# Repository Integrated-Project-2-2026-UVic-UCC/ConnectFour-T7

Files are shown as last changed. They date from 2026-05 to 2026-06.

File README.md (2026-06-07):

<div align="center">

# Autonomous Connect 4 Machine
### Integrated Project II · Mechatronics Engineering · UVic-UCC 2026




[]()
[]()

*A fully autonomous physical Connect 4 machine: the ESP32 detects each piece drop with photoelectric sensors, decides the best move, and physically delivers the piece using a motorized lead screw dispenser.*

</div>

---

## Table of Contents

- [About the Project](#about-the-project)
- [How It Works](#how-it-works)
- [Mechanical Design](#mechanical-design)
- [Electronics](#electronics)
- [Software](#software)
- [Hardware Components](#hardware-components)
- [Getting Started](#getting-started)
- [Current Status](#current-status)
- [Team](#team)
- [License](#license)

---

## About the Project

This project is developed as part of **Integrated Project II** in the **Mechatronics Engineering** degree at the Universitat de Vic – Universitat Central de Catalunya (UVic-UCC).

The goal is to build a machine that plays **Connect 4 autonomously** against a human opponent. The machine detects the human's move through **photoelectric sensors**, decides which column to play, moves a **3D-printed piece dispenser** along a lead screw to the correct position, and drops a piece with a **servo motor** — all controlled by an **ESP32**.

The robot does not use an artificial intelligence engine. Instead, it follows a predefined logical strategy: win if possible, block the opponent, or otherwise play an available column. All game communication is handled through the **Serial Monitor**.

---

## How It Works

```
Human drops a piece
        │
        ▼
Photoelectric sensor (one per column)
detects the piece passing through
        │
        ▼
ESP32 updates the board state
        │
        ▼
Software selects the column to play
(win > block > random available column)
        │
        ▼
Stepper motor moves the dispenser
along the lead screw to the target column
        │
        ▼
Servo motor pushes the ramp and releases one piece
        │
        ▼
Piece falls into the board
        │
        ▼
Game state shown through the Serial Monitor
```

> **Note:** Piece recovery and board reset are performed manually between games.

---

## Mechanical Design

The mechanical design is organized into two main assemblies, all modeled in PTC Creo, exported as STL for 3D printing, and documented with technical drawings.

**Board structure assembly** — represents the game board and holds the structure upright:
- **Foot L** and **Foot R** — the two legs of the structure
- **Bottom Cover** — closes the structure and assembles onto the base
- **Connect 4** — the main board frame with the 7 × 6 grid of columns
- **Connect 4 Cover** — the front cover that closes the playing grid

**Dispenser and linear-motion assembly** — carries and releases the pieces:
- **Support Foot** and **Dispenser Support Bar** — hold the dispenser in place
- **Motor Support** — holds the stepper motor at one end of the lead screw
- **Bearing Support** — holds the bearing at the opposite end of the lead screw
- **Dispenser Part 1** and **Dispenser Part 2** — form the dispenser body

The pieces are stored horizontally inside the dispenser. To drop a piece, an internal ramp reorients it from horizontal to vertical so it falls correctly into the selected column, and a servo motor pushes the ramp downward to release one piece at a time. The whole dispenser slides along the lead screw to align with any of the seven columns.

---

## Electronics

The electrical system is based on an **ESP32** microcontroller, which manages all inputs and outputs of the robot:
- Reads the photoelectric (IR) sensors to detect the column played by the human
- Controls the stepper motor driver to move the dispenser horizontally
- Activates the servo motor to release a piece
- Provides the electrical interface between software, sensors, and actuators

The ESP32 works with 3.3 V logic, and an external power supply feeds the stepper motor and servo. All components share a common ground to keep a correct signal reference. The schematic was designed with EasyEDA.

---

## Software

- **Microcontroller:** ESP32
- **Language:** C++ (Arduino)
- **Key modules:**
  - `detection` — reads photoelectric sensors and maps them to a column index
  - `motion` — stepper step generation and position control
  - `servo` — piece release timing and control
  - `game` — board state, win/block detection, move selection
  - `serial` — Serial Monitor communication (prompts and game status)

The board is handled as a 6-row by 7-column matrix. The code initializes the board, manages player and robot moves, validates that columns are not full, and detects winning conditions (horizontal, vertical, and diagonal) as well as draws.

Two final versions of the system are provided:
- **Automatic Detection Mode** — the player's move is detected automatically by the photoelectric sensors, which identify the played column.
- **Manual Input Mode** — a backup version where the player enters the column number through the Serial Monitor, in case the sensors fail.

---

## Hardware Components

| Component | Description | 
|---|---|
| ESP32 | Main microcontroller — game logic, motor and sensor control |
| NEMA17 stepper motor | X-axis movement via lead screw |
| Stepper driver | Motor driver for step/direction control |
| Lead screw | Linear X-axis mechanism |
| Linear guide + carriage | Supports and guides the dispenser |
| 9g micro servo | Releases one piece at a time from the dispenser |
| Photoelectric / IR sensors | One per column, detect the played column |
| Series resistors | Required for reliable photoelectric detection |
| External power supply | Powers the stepper motor and servo |
| Connect 4 board | 7 × 6 grid with sensor holes at the top |

---

## Getting Started

### Prerequisites

- [Arduino IDE](https://www.arduino.cc/en/software) or [PlatformIO](https://platformio.org/) with ESP32 board support
- ESP32 board package installed
- Required libraries:
  - `AccelStepper` — stepper motor control
  - `ESP32Servo` — servo control

### Flash to ESP32

1. Open the project in Arduino IDE or PlatformIO
2. Select board: **ESP32 Dev Module**
3. Connect ESP32 via USB
4. Upload

> **Warning:** Make sure the sensors, motor, and servo are connected before powering on, and that the external power supply for the motor and servo is on.

---

## Current Status

| Phase | Task | Status |
|---|---|---|
| 1 | Initial design and planning | Done |
| 2 | Component procurement | Done |
| 3 | 3D printing — dispenser and mechanical parts | Done |
| 3 | Electronics wiring and assembly | Done |
| 3 | Individual component testing (sensors, motor, servo) | Done |
| 4 | Full system integration | Done |
| 4 | Software validation on real hardware | Done |
| 5 | Final calibration and demo | Done |

---

## Team

| Name | Role |
|---|---|
| Arnau Arcarons | Project Manager |
| Pau Vila | Mechanical Leader |
| Victor Ruiz | Electronics Leader |
| Albert Llimós | Programming Leader |

> Project supervised by Moisès and Clara, faculty of Mechatronics Engineering at UVic-UCC.

---

## License

This project is licensed under the **GNU General Public License v3.0**.
See the [`LICENSE`](LICENSE) file for full details.

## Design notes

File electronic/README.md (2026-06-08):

# Electronics

This folder contains the final electronic documentation of the autonomous Connect Four robot developed by Team 7 for the Integrated Projects II course at UVic-UCC.

The electronic system connects the control software with the physical hardware of the machine. It is responsible for reading the player move sensors, controlling the stepper motor driver, activating the piece dispenser servo, and managing the basic electrical interface between all components.

---

## Folder Contents

This folder includes the main electrical schematic of the prototype and the datasheets of the key electronic components used in the system.

| File | Description |
|---|---|
| `IP_2.pdf` | Final electrical schematic of the system, created with EasyEDA. It shows the connections between the ESP32 controller, sensors, stepper driver, servo motor, power supply and common ground. |
| `A1.3 esp32-s3_datasheet_en.pdf` | Datasheet of the ESP32-S3 microcontroller, used as the main controller reference for GPIO, electrical characteristics and pin functions. |
| `A4988.PDF` | Datasheet/reference document for the A4988 stepper motor driver used to control the NEMA17 stepper motor. |
| `README.md` | Documentation file describing the purpose and contents of the electronics folder. |

---

## Electronic System Overview

The electronic system is centred on the ESP32 microcontroller. The ESP32 receives input signals from the column sensors and sends control signals to the actuators of the machine.

The system performs the following main tasks:

1. Detecting the column selected by the human player.
2. Sending STEP and DIR signals to the A4988 stepper motor driver.
3. Moving the NEMA17 stepper motor along the horizontal axis.
4. Activating the 9 g servo motor to release one piece.
5. Reading the limit switch used as a mechanical reference.
6. Coordinating the electrical behaviour of the full prototype.

---

## Main Electronic Components

| Component | Function | Interface |
|---|---|---|
| ESP32 / ESP32-S3 | Main controller of the system | GPIO / PWM / Serial |
| A4988 stepper motor driver | Controls the NEMA17 stepper motor | STEP / DIR |
| NEMA17 stepper motor | Moves the dispenser horizontally | Driven by A4988 |
| 9 g servo motor | Opens and closes the dispenser gate | PWM |
| Column sensors | Detect the column used by the human player | Digital inputs |
| Limit switch | Provides a reference position for the axis | Digital input |
| External power supply | Powers the motor and actuator system | Power input |
| Common ground | Shared electrical reference | GND |

---

## Electrical Schematic

The electrical schematic is provided in:

```text
IP_2.pdf

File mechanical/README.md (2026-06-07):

## Project Description
This repository contains the mechanical design of a robot capable of playing the Connect Four game. The mechanical system provides the physical structure of the game board and the mechanism responsible for storing, positioning, and dropping the playing pieces into the correct column.

The design is organized into two main assemblies: the board structure, which holds the playing grid, and the dispenser and linear-motion assembly, which moves along the board and releases the pieces one by one.

## Project Structure
During the development process, the mechanical design was divided into two main assemblies:
1. Board structure assembly
2. Dispenser and linear-motion assembly

Each part was modeled in PTC Creo, exported as an STL file for 3D printing, and documented with its corresponding technical drawing.

## Board Structure Assembly
This assembly represents the game board and provides the supporting frame of the robot. It is composed of:
* **Foot L** and **Foot R** – the two legs that hold the structure upright
* **Bottom Cover** – the lower cover that closes the structure and is assembled onto the base
* **Connect 4** – the main board frame containing the 6×7 grid of columns
* **Connect 4 Cover** – the front cover that closes the playing grid

The two feet and the bottom cover are assembled together to form the base, onto which the board frame and its cover are mounted.

## Dispenser and Linear-Motion Assembly
The second assembly is mounted on its own support and is responsible for carrying and releasing the pieces. It includes:
* **Support Foot** – the additional leg of this assembly
* **Dispenser Support Bar** – the bar that links the support and holds the dispenser in place
* **Motor Support** – the bracket that holds the stepper motor at one end of the lead screw
* **Bearing Support** – the bracket that holds the bearing at the opposite end of the lead screw
* **Dispenser Part 1**, **Dispenser Part 2** and the **Dispenser Support Bar** – the parts that form the dispenser body

A support element attaches the carriage and its bushing to the dispenser, allowing the whole dispenser to slide along the lead screw.

## Piece Dispensing Mechanism
The pieces are stored horizontally inside the dispenser. To drop a piece, the dispenser uses an internal ramp that reorients the piece from a horizontal to a vertical position, so that it can fall correctly into the selected column.

A servo motor mounted on the dispenser pushes the ramp downward, releasing one piece at a time.

## Linear-Motion System
The dispenser moves horizontally along the board by means of a lead screw (worm screw):
* The **Motor Support** holds the stepper motor at the beginning of the lead screw
* The **Bearing Support** holds the bearing at the end of the lead screw
* The carriage, attached to the dispenser, travels along the screw to position the dispenser over the desired column

This allows the robot to align the dispenser precisely with any of the seven columns before releasing a piece.

## File Formats and Repository Structure
For each part, three file formats are provided. The files are organized into three folders:
* **STL_3D_Parts** – the 3D models in STL format, ready for 3D printing
* **Creo_Files** – the original PTC Creo part files (`.prt`), including the Creo session trail file
* **Technical_Drawings** – the technical drawings (blueprints) of each part in PDF format

## Current Project Status
The mechanical design has reached a functional state where:
* The board structure and base are fully modeled and assembled
* The dispenser and its ramp mechanism convert pieces from horizontal to vertical for correct release
* The servo-driven dropping mechanism has been integrated into the dispenser
* The linear-motion system positions the dispenser over each column using a lead screw
* All parts are documented with STL models, Creo files, and technical drawings ready for manufacturing

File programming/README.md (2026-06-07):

## Project Description

This project implements the control software for a robot capable of playing the Connect Four game. The program acts as the robot's control system, managing the game logic, player interaction, and the robot's decision-making process.

The system allows a complete game between the player and the robot by validating moves, managing turns, and determining the final result (win, loss, or draw).

## Project Structure

During the development process, the project was divided into three main parts:

1. Robot decision-making
2. Player interaction
3. Mechanical control and piece launching

In the final version, the implementation of an artificial intelligence system was not considered necessary. Instead, the robot follows a predefined logical strategy to make its decisions.

## Code Functionality

The code manages a 6-row by 7-column matrix that represents the game board. The main functionalities include:

* Board initialization
* Management of player and robot moves
* Validation of moves to ensure that columns are not full
* Detection of winning conditions (horizontal, vertical, and diagonal)
* Detection of draw situations when the board is full

## Robot Decision Logic

The robot follows a simple three-step strategy:

1. Check for an immediate winning move
2. Block the player if they are about to win
3. Select a random available column if no better option is found

## Player Interaction

The LCD display originally planned for the project was not implemented. Instead, all communication with the player is performed through the computer's Serial Monitor.

The serial interface allows the user to:

* Select which player starts the game
* Enter player moves
* Display game status messages
* Restart the game after a match ends

## Sensor and Mechanical Testing

Several tests were carried out to validate the operation of the photoelectric sensors. Although the sensors work correctly in most situations, occasional detection failures were observed.

For this reason, the development process was divided into several independent test programs:

* Sensor testing code
* Stepper motor movement testing code
* Servo-based piece launching testing code
* Main logic code that integrates player interaction and the robot's decision-making strategy

## Final Implementations

Two final versions of the system were developed:

### Automatic Detection Mode

In this version, the player's move is detected automatically by a photoelectric sensor, which identifies the column where the piece has been dropped. The robot then analyzes the board and performs its move according to the predefined logic.

### Manual Input Mode

Since the sensors may occasionally fail, a backup version was also developed. In this mode, the player enters the column number through the Serial Monitor after each move. The robot then updates the board, analyzes the game state, and performs its move using the same logical decision-making process.

## Current Project Status

The project has reached a functional state where:

* The robot can play a complete game of Connect Four
* Player interaction is managed through the Serial Monitor
* The mechanical launching system has been tested
* Sensor detection has been implemented and evaluated
* A backup manual mode ensures reliable operation even if the sensors fail

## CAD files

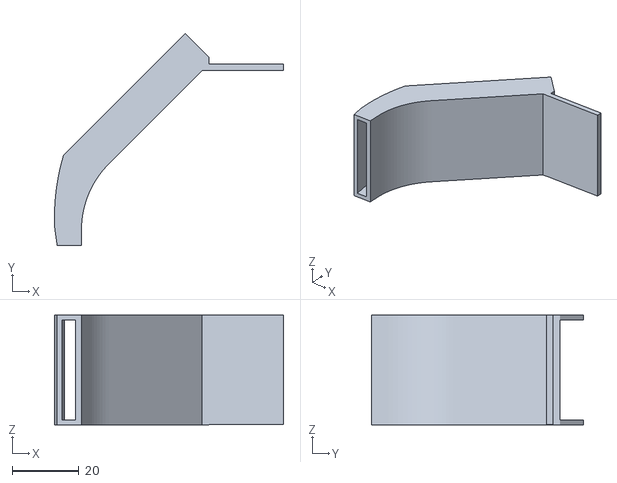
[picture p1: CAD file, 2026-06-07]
mechanical/STL_3D_Parts/dispenser_part_2.stl
68.7 x 63.5 x 33.0

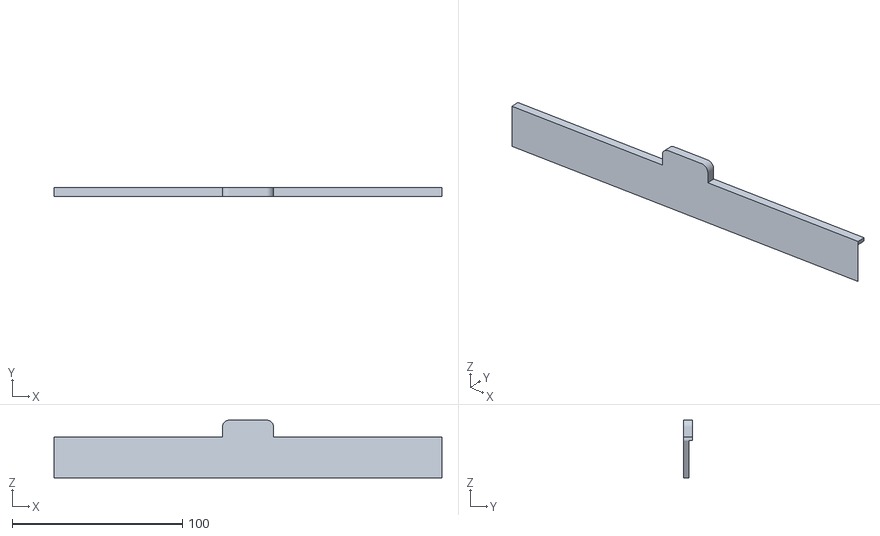
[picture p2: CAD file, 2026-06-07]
mechanical/STL_3D_Parts/bottom_cover.stl
228.0 x 5.00 x 34.0

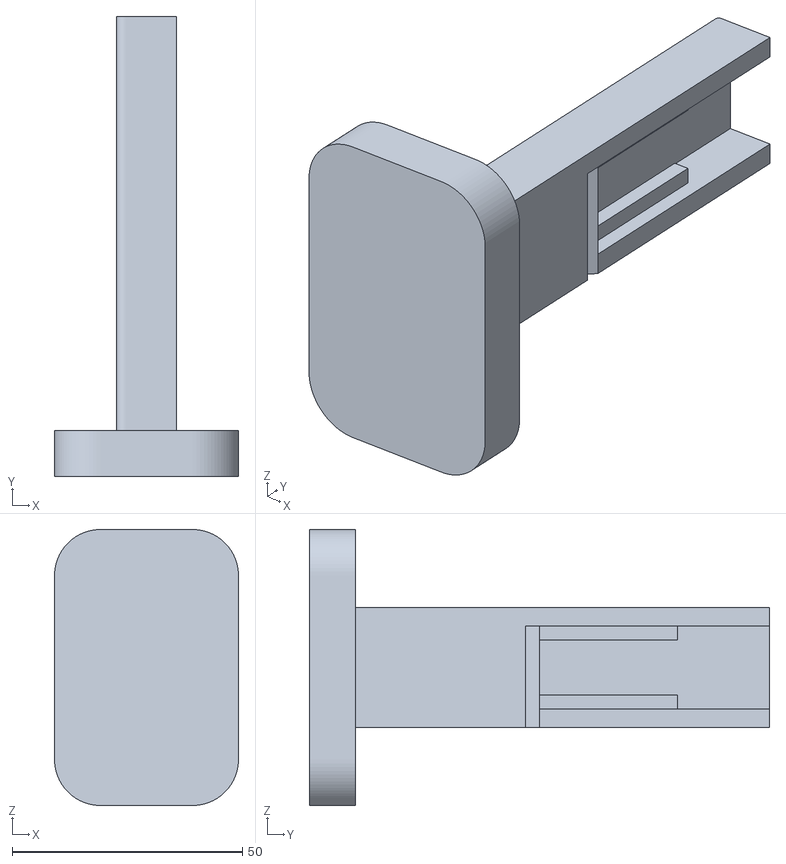
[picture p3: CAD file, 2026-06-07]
mechanical/STL_3D_Parts/foot_r.stl
40.0 x 100.0 x 60.0

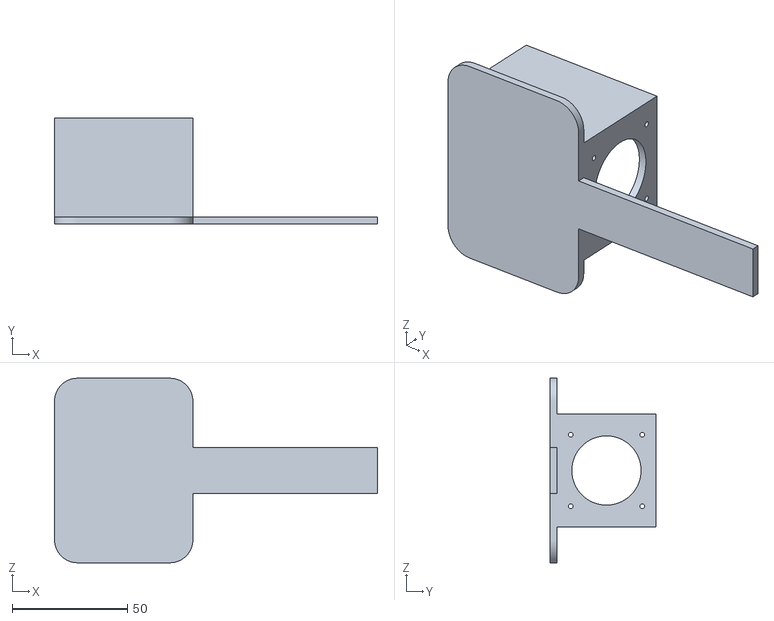
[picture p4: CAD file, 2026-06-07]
mechanical/STL_3D_Parts/motor_support.stl
140.0 x 46.0 x 80.0

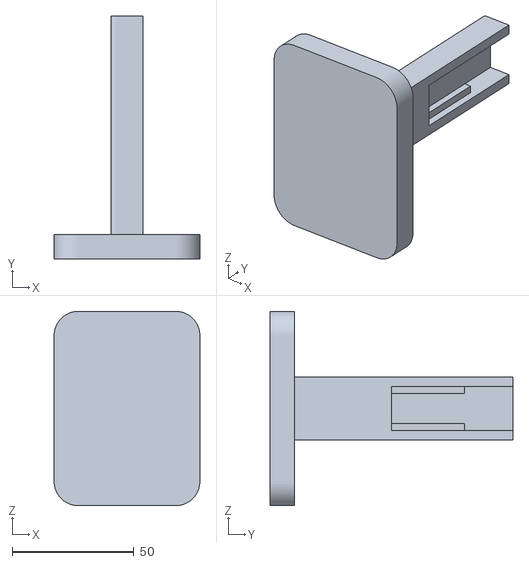
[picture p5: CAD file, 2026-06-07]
mechanical/STL_3D_Parts/suport_foot.stl
60.0 x 100.0 x 80.0

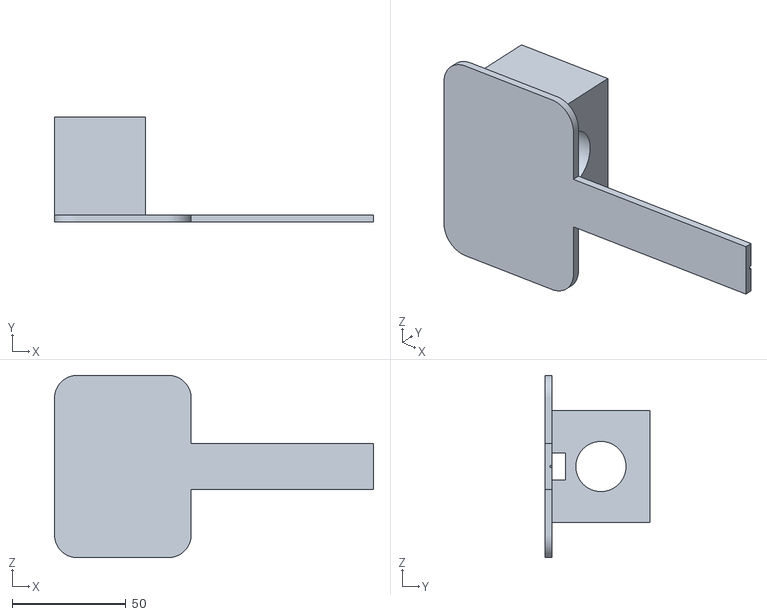
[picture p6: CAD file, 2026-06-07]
mechanical/STL_3D_Parts/bearing_support.stl
140.0 x 46.0 x 80.0

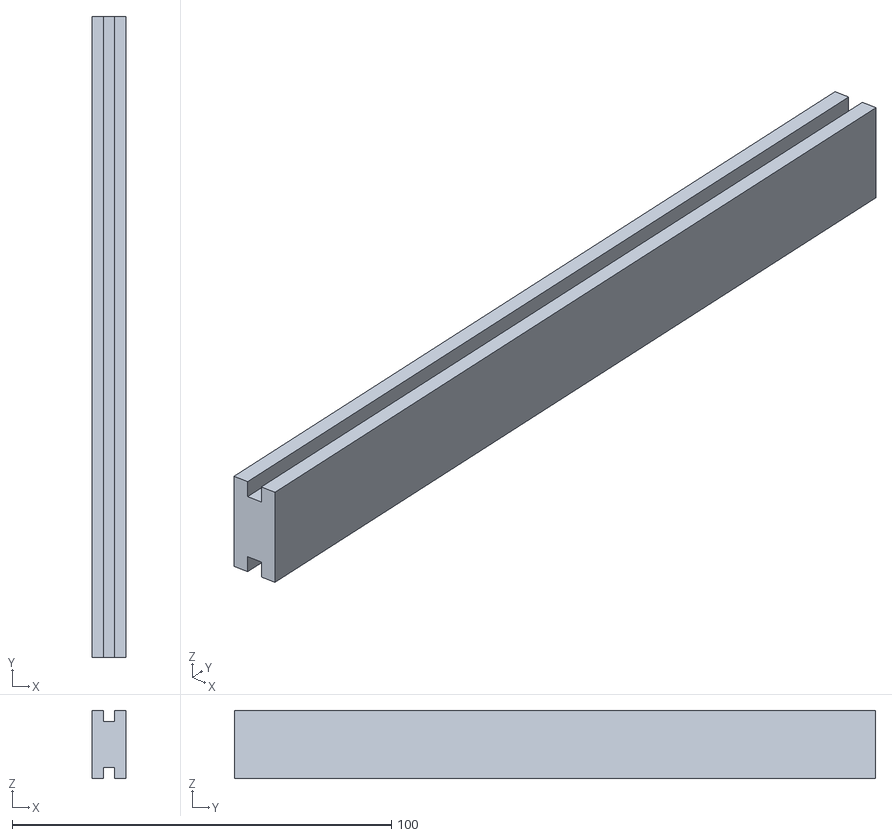
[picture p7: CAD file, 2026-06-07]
mechanical/STL_3D_Parts/dispenser_support_bar.stl
9.00 x 169.0 x 18.0

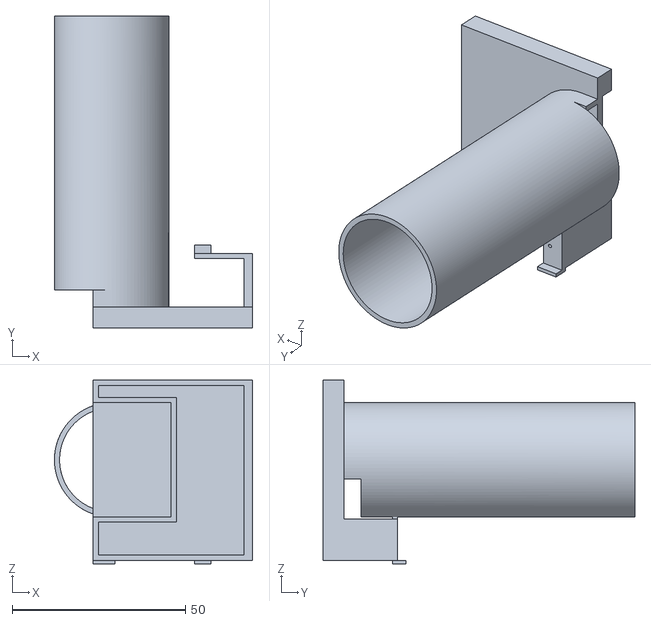
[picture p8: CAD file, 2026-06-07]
mechanical/STL_3D_Parts/dispenser_part_1.stl
57.2 x 90.0 x 53.0

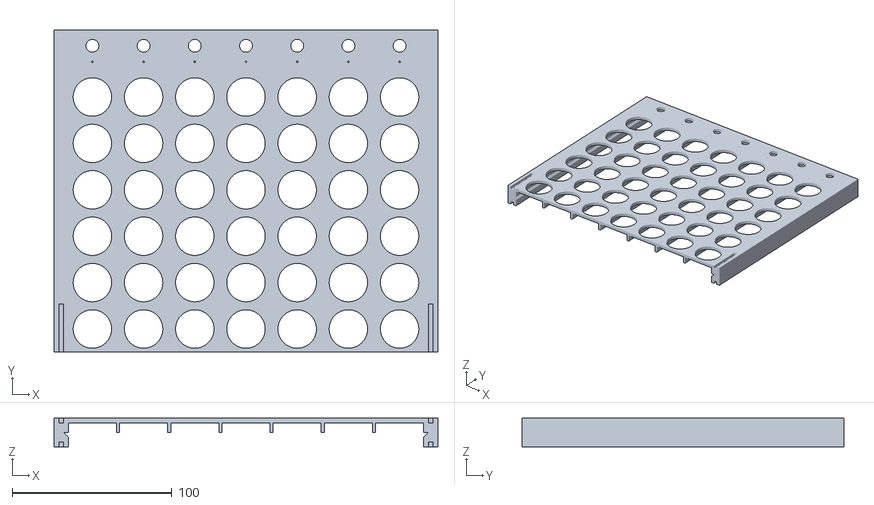
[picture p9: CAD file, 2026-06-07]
mechanical/STL_3D_Parts/connect_4_cover.stl
240.0 x 201.5 x 18.0

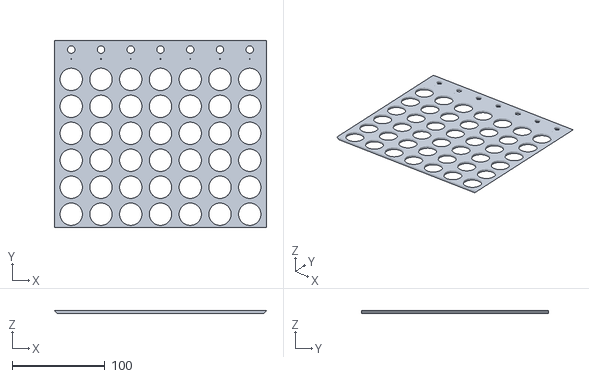
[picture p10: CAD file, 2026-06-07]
mechanical/STL_3D_Parts/connect_4.stl
228.0 x 201.5 x 3.00

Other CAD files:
mechanical/STL_3D_Parts/foot_l.stl

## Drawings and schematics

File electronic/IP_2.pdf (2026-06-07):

A | A
B | B

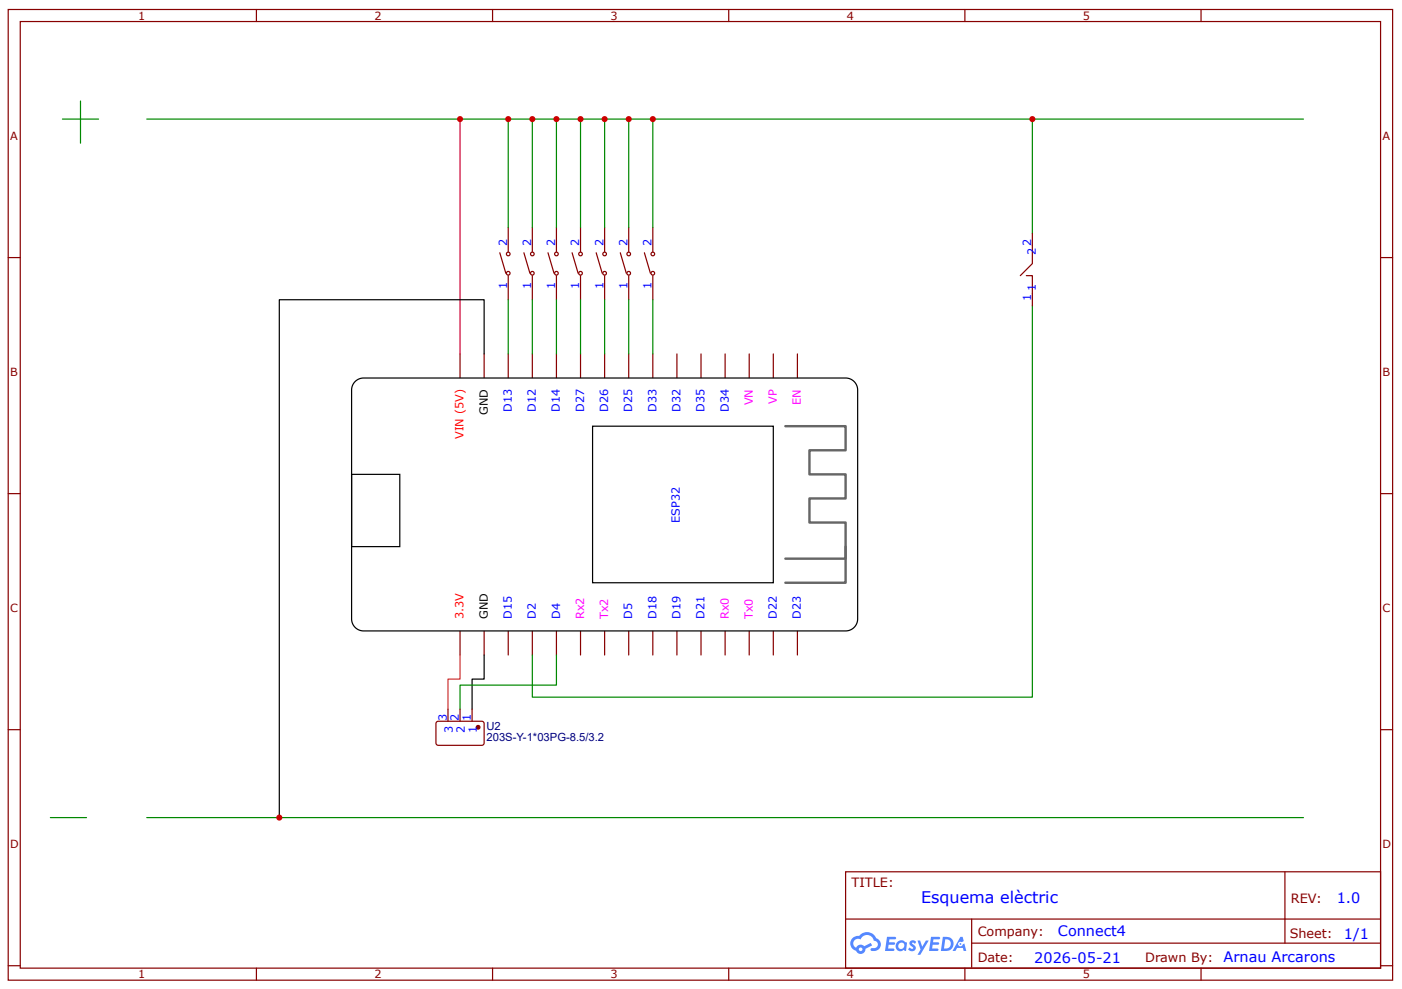
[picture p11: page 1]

Drawn By: Arnau Arcarons

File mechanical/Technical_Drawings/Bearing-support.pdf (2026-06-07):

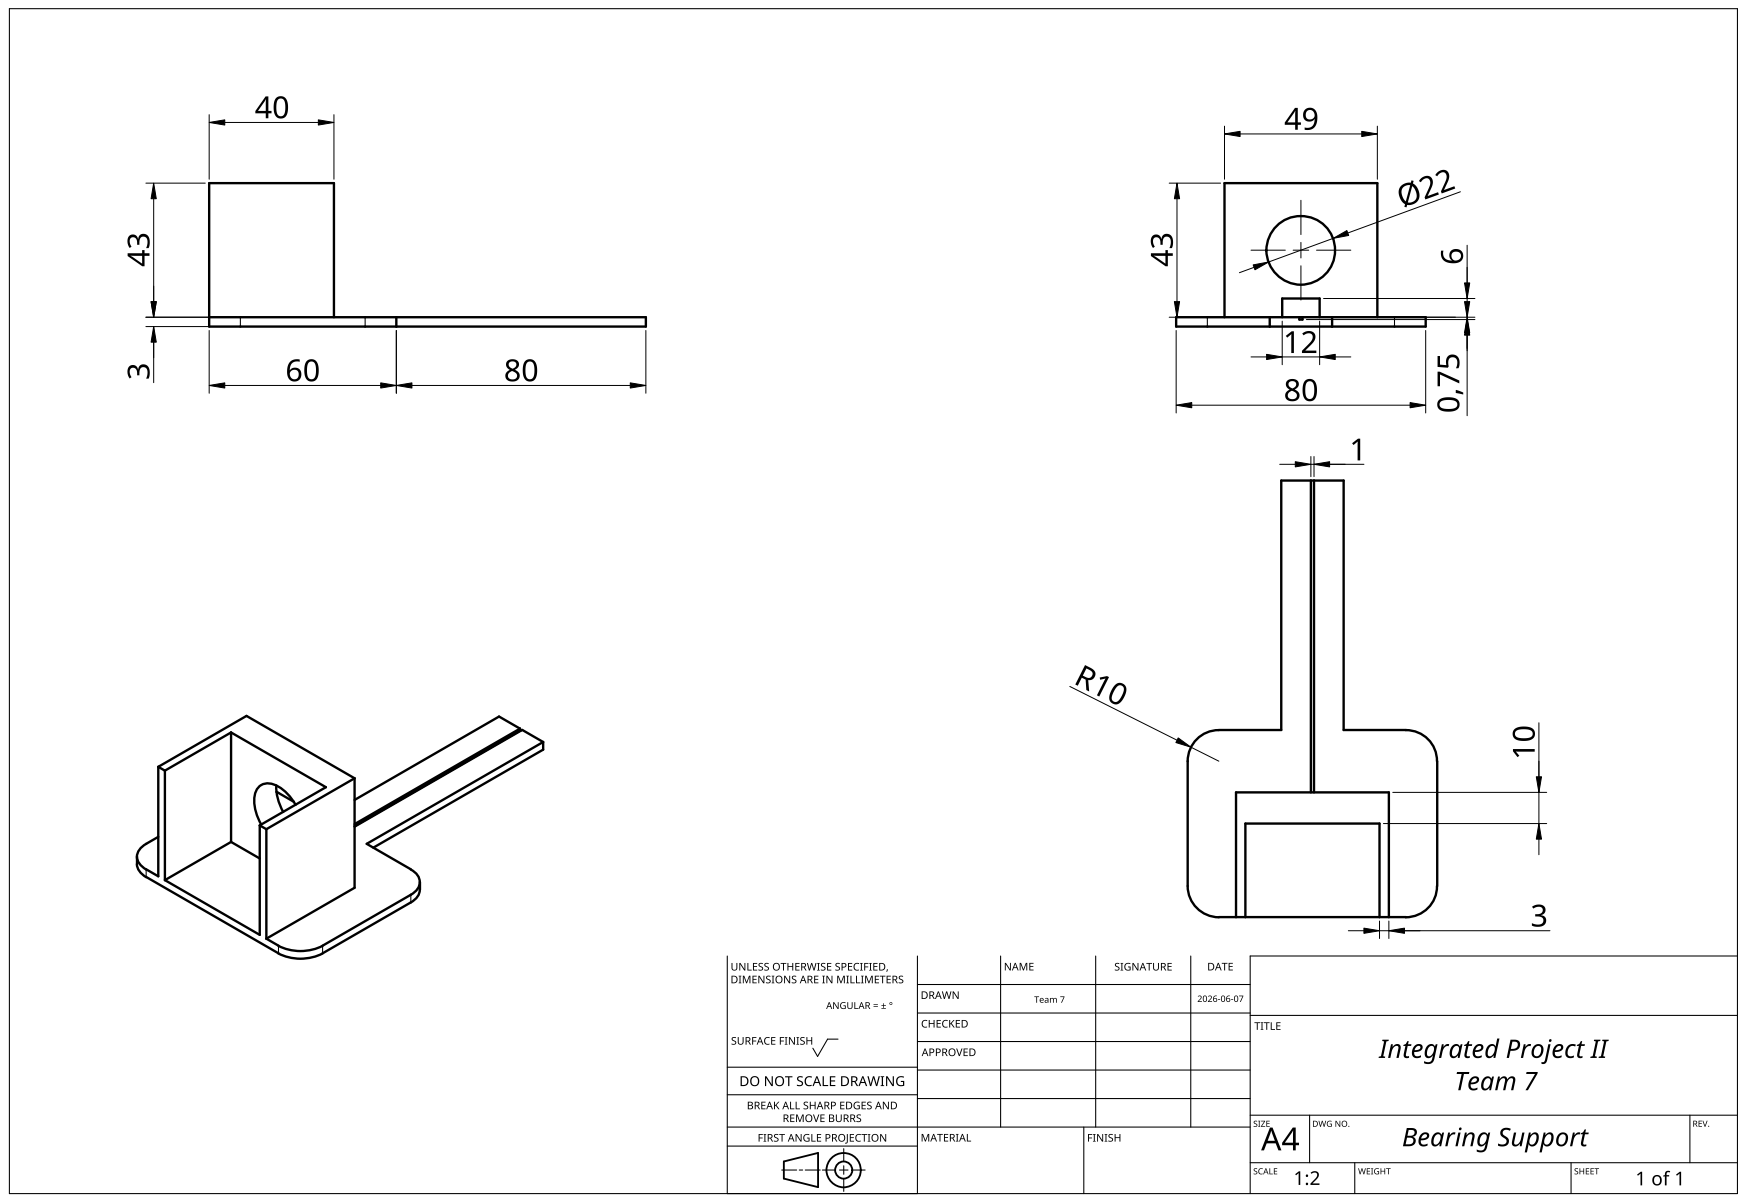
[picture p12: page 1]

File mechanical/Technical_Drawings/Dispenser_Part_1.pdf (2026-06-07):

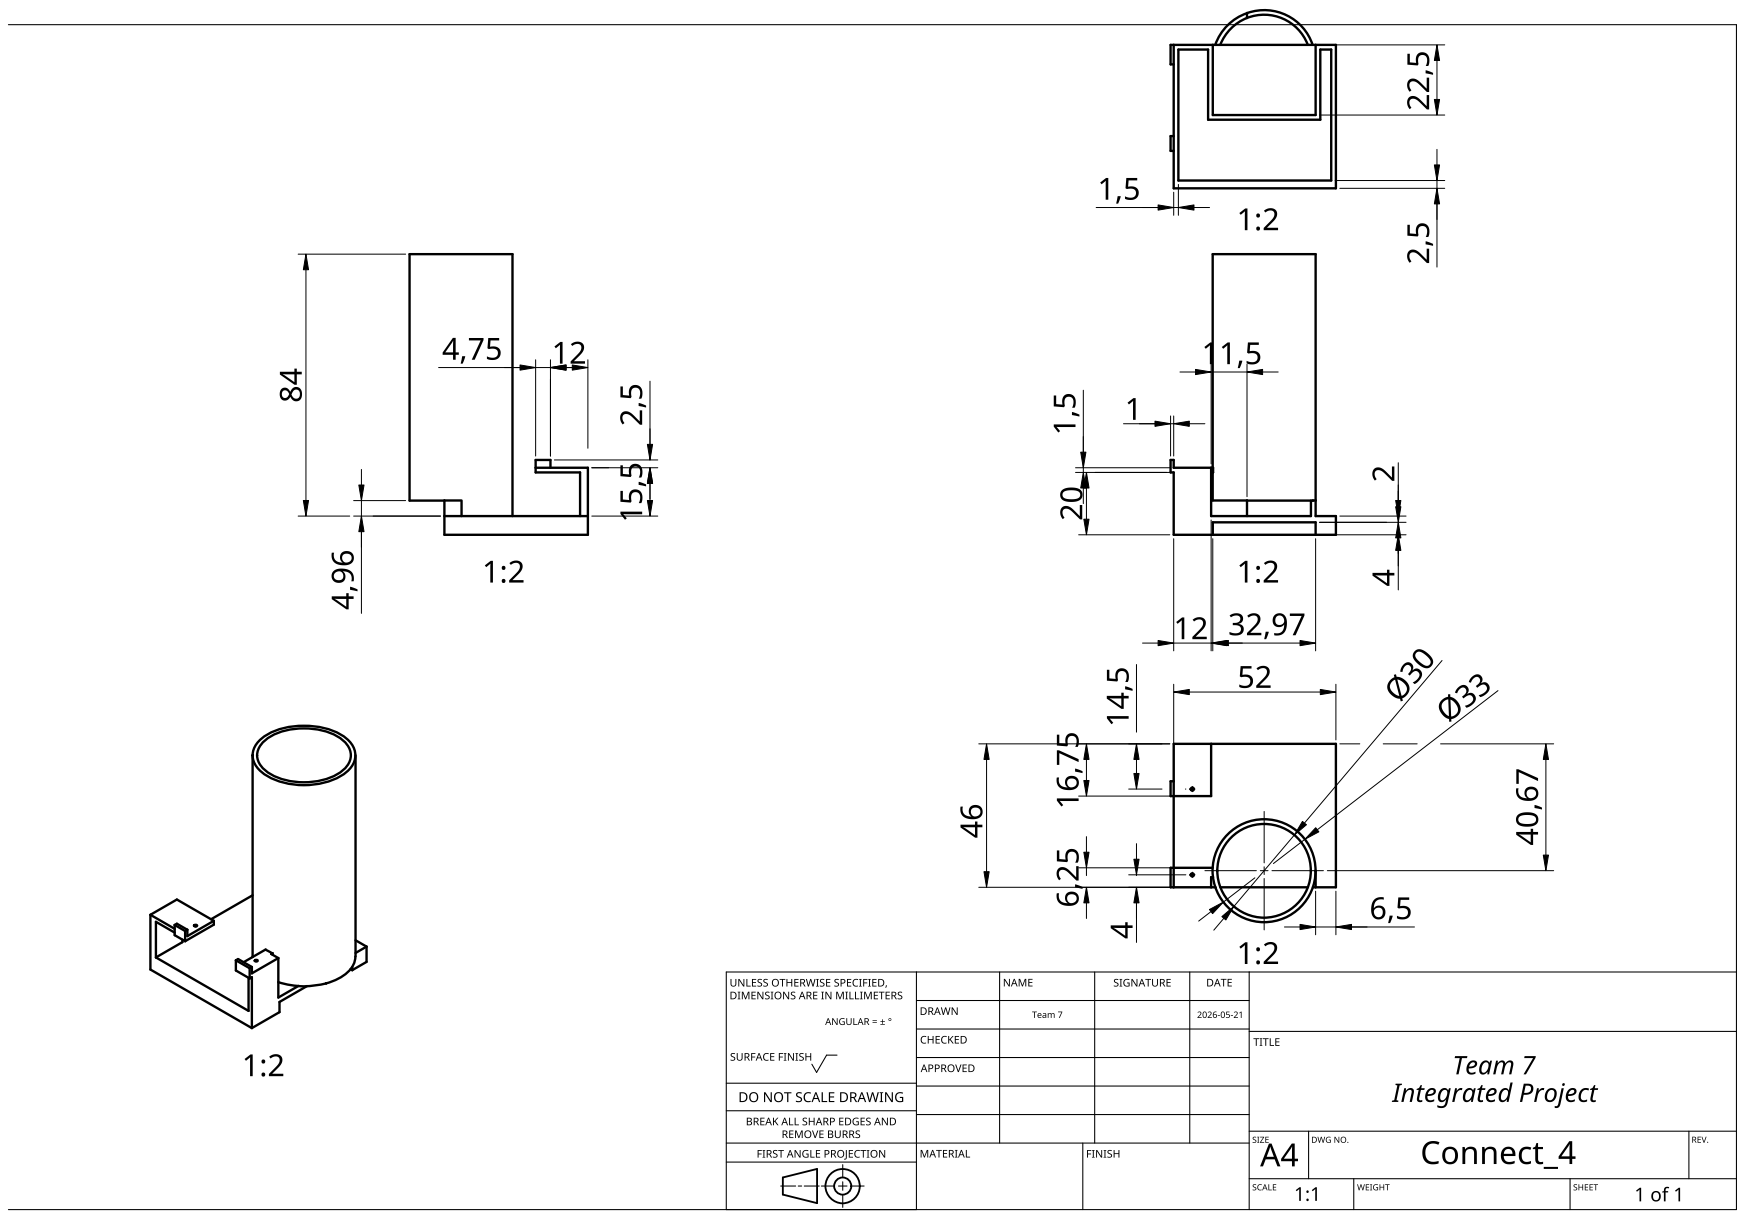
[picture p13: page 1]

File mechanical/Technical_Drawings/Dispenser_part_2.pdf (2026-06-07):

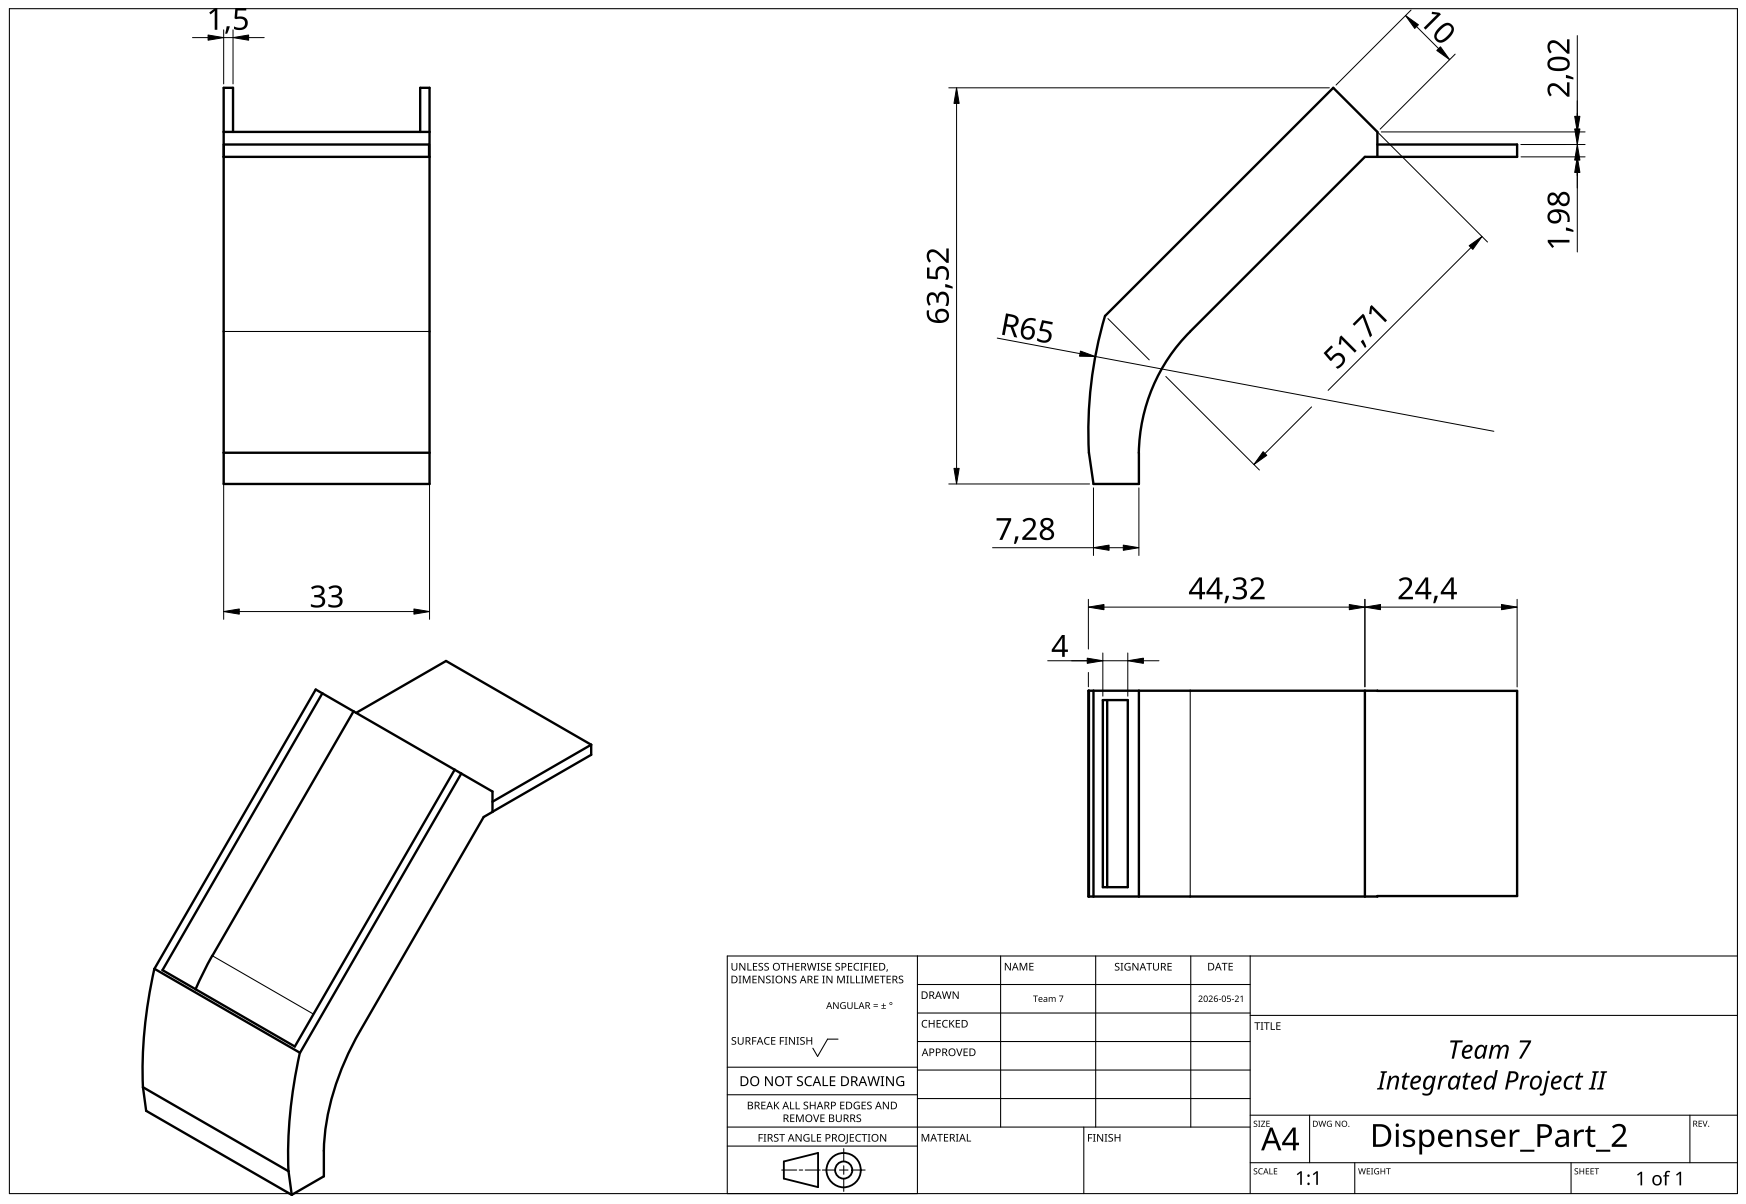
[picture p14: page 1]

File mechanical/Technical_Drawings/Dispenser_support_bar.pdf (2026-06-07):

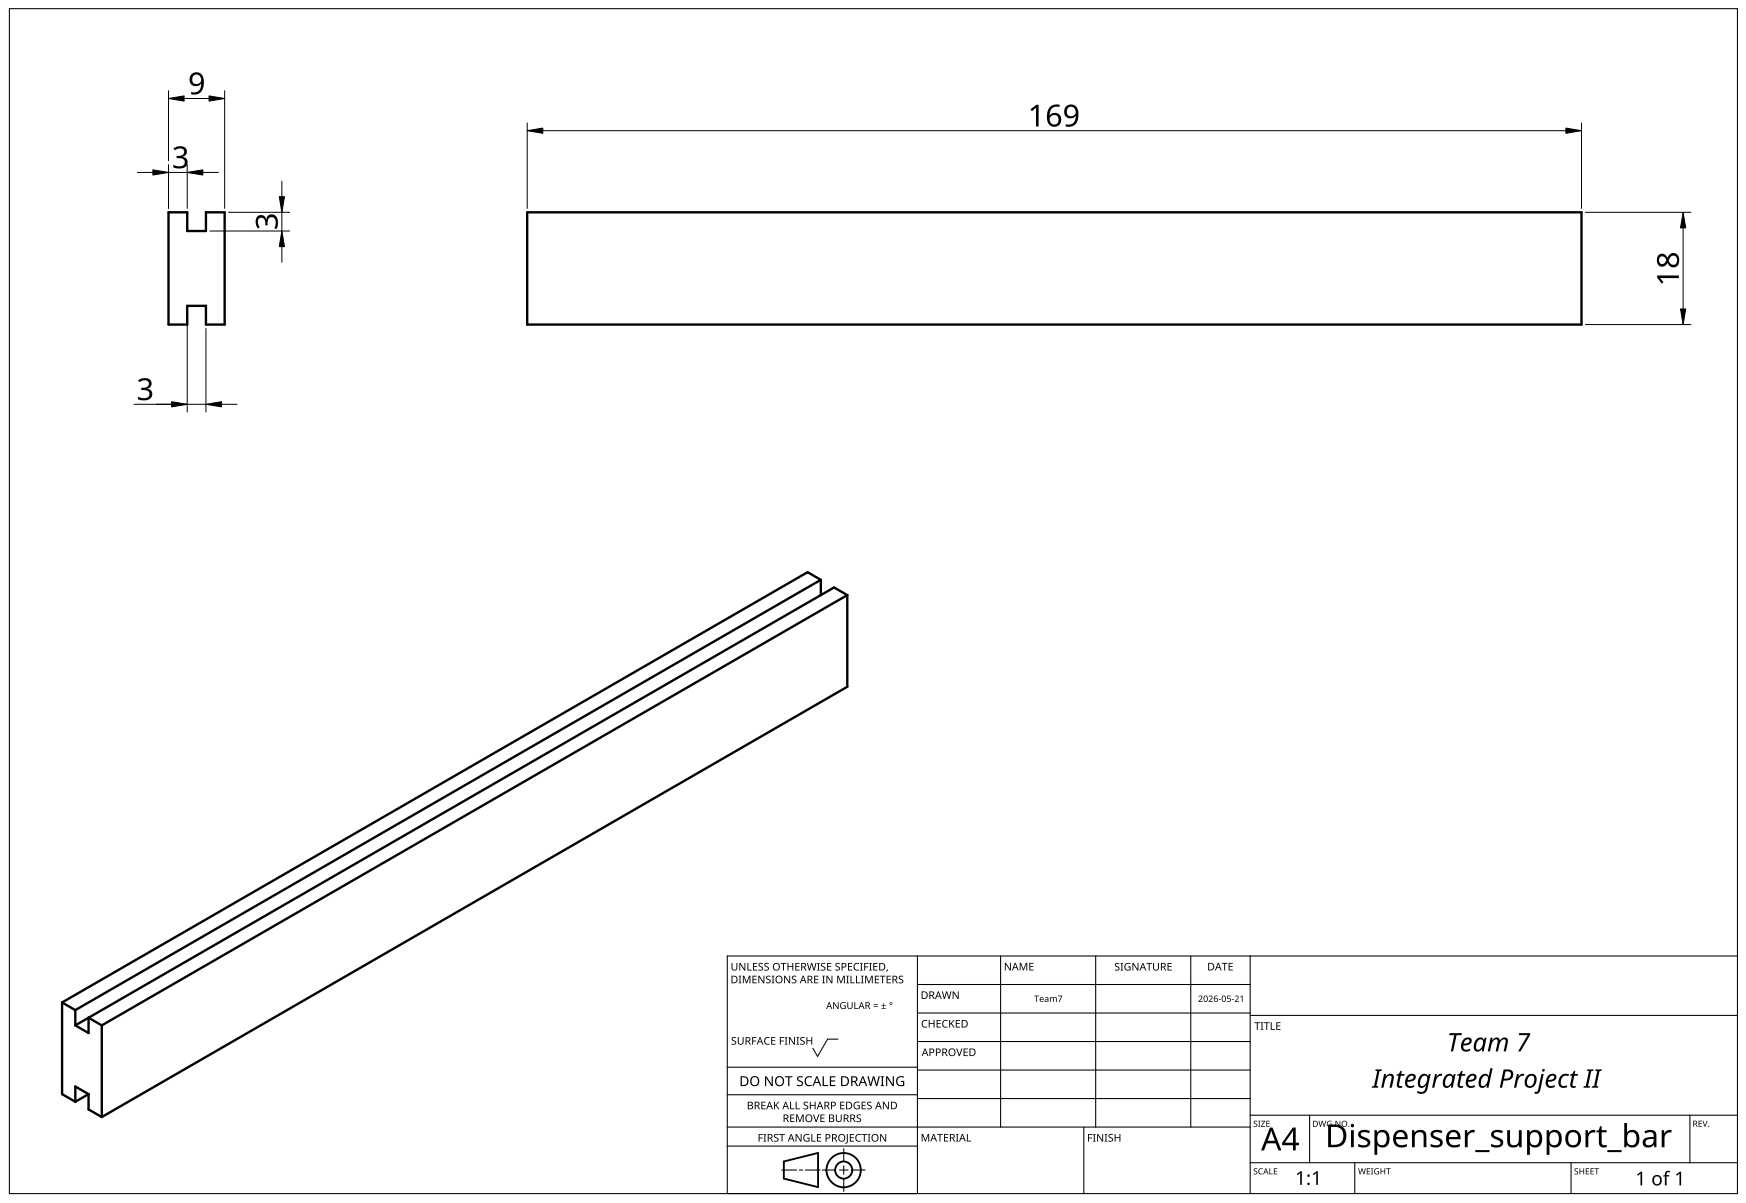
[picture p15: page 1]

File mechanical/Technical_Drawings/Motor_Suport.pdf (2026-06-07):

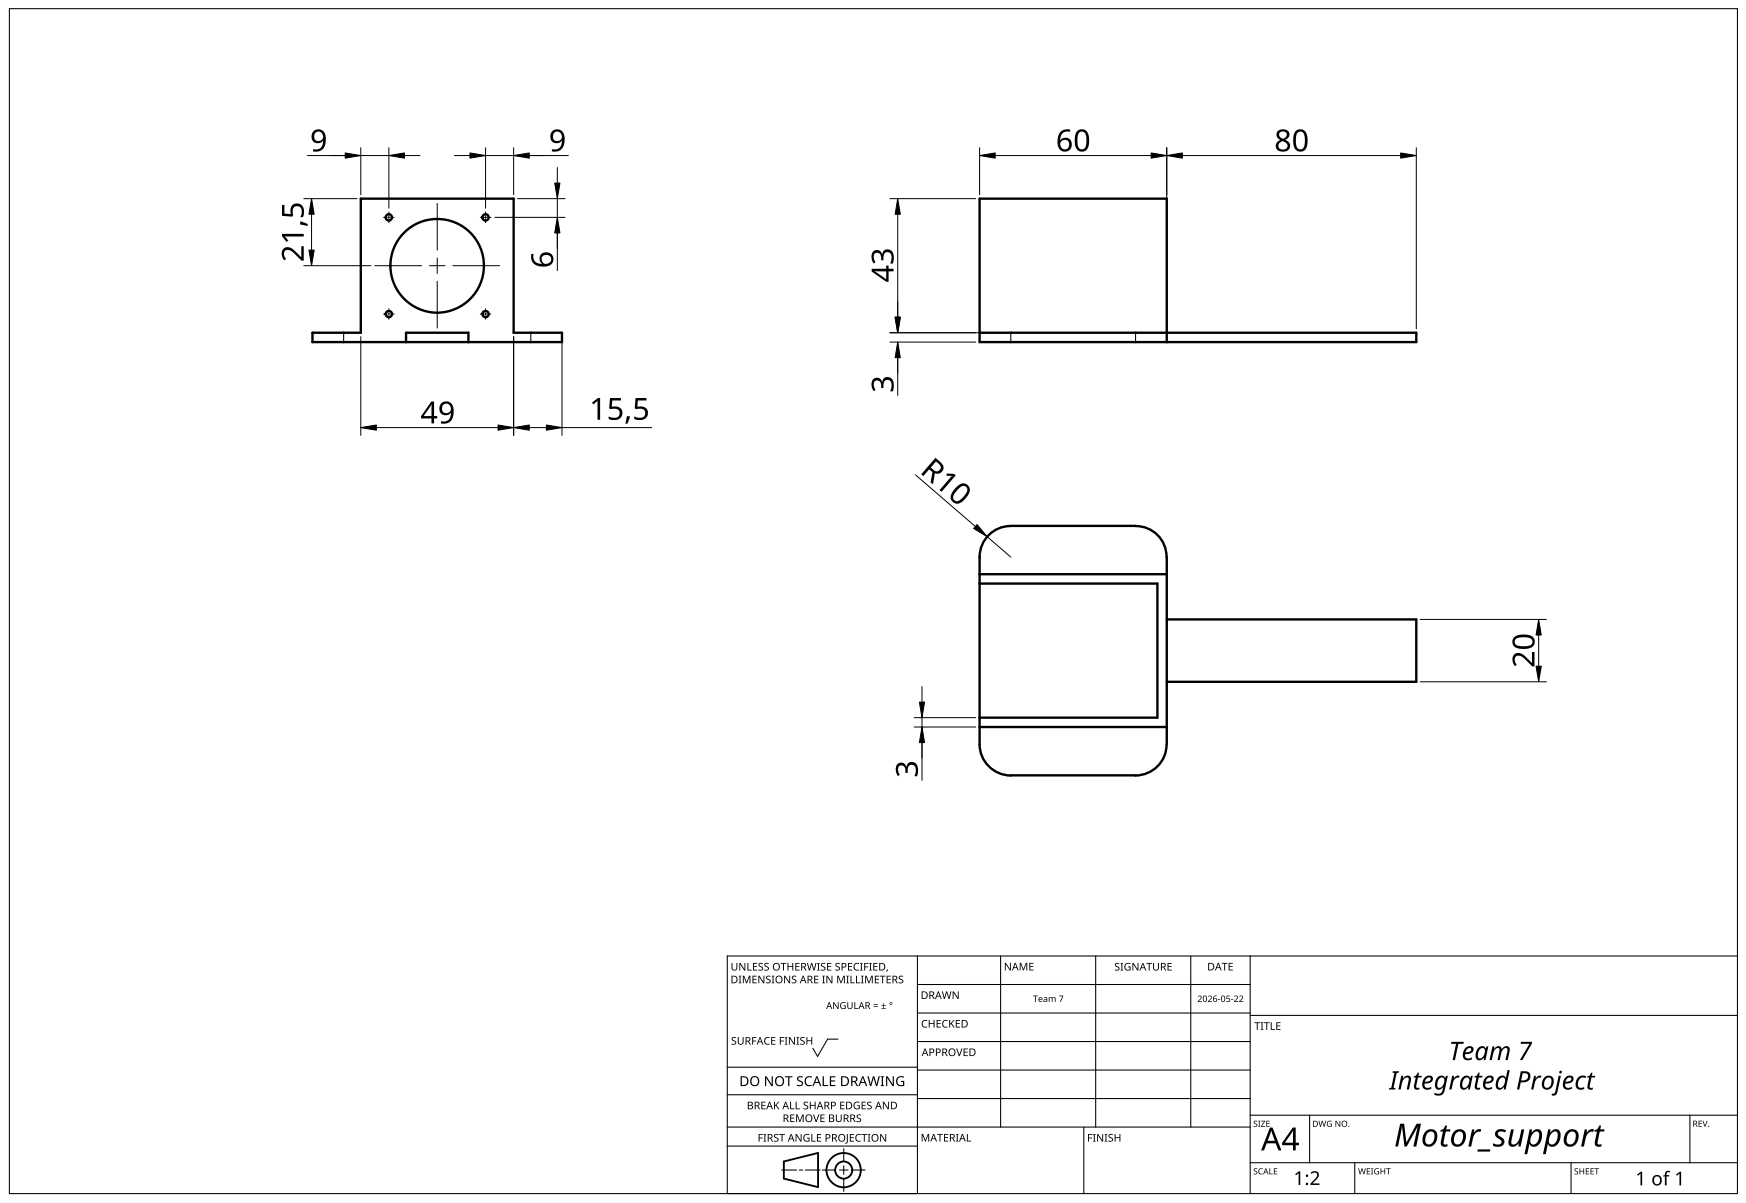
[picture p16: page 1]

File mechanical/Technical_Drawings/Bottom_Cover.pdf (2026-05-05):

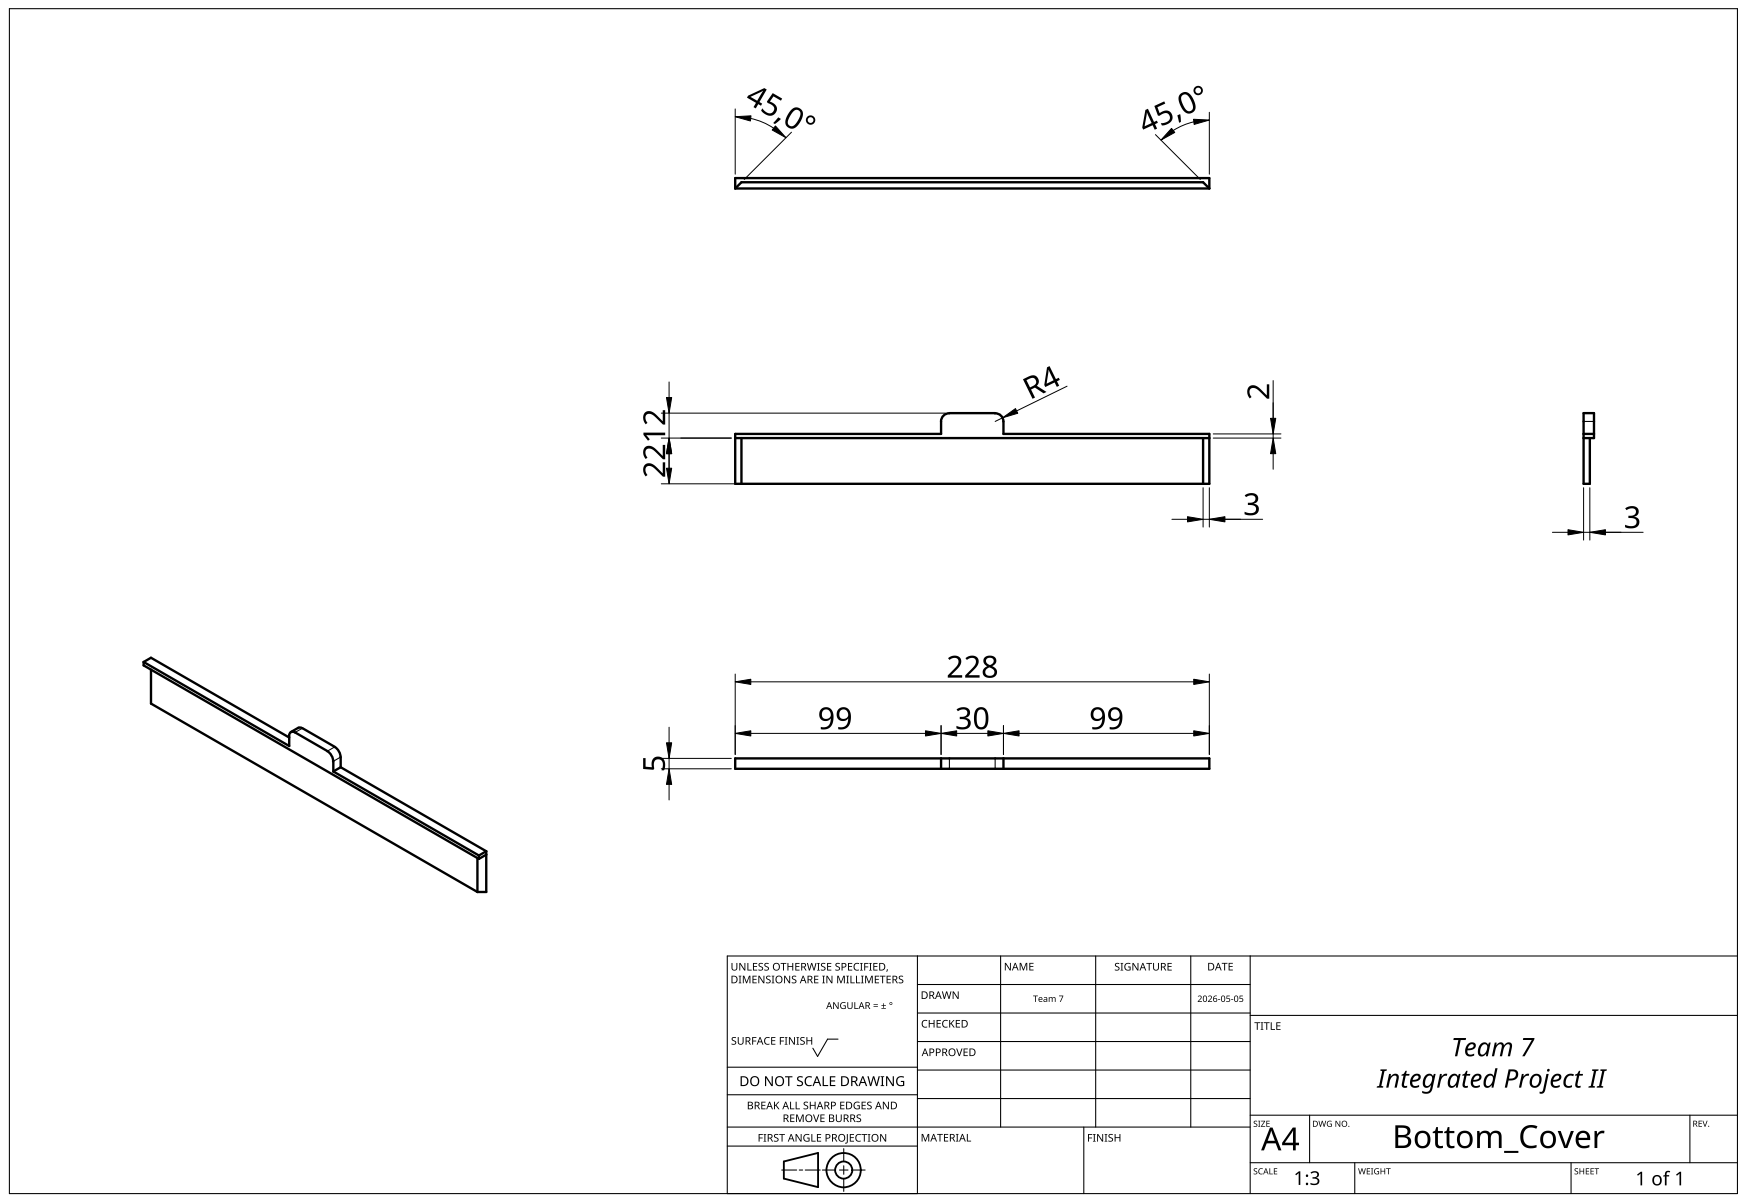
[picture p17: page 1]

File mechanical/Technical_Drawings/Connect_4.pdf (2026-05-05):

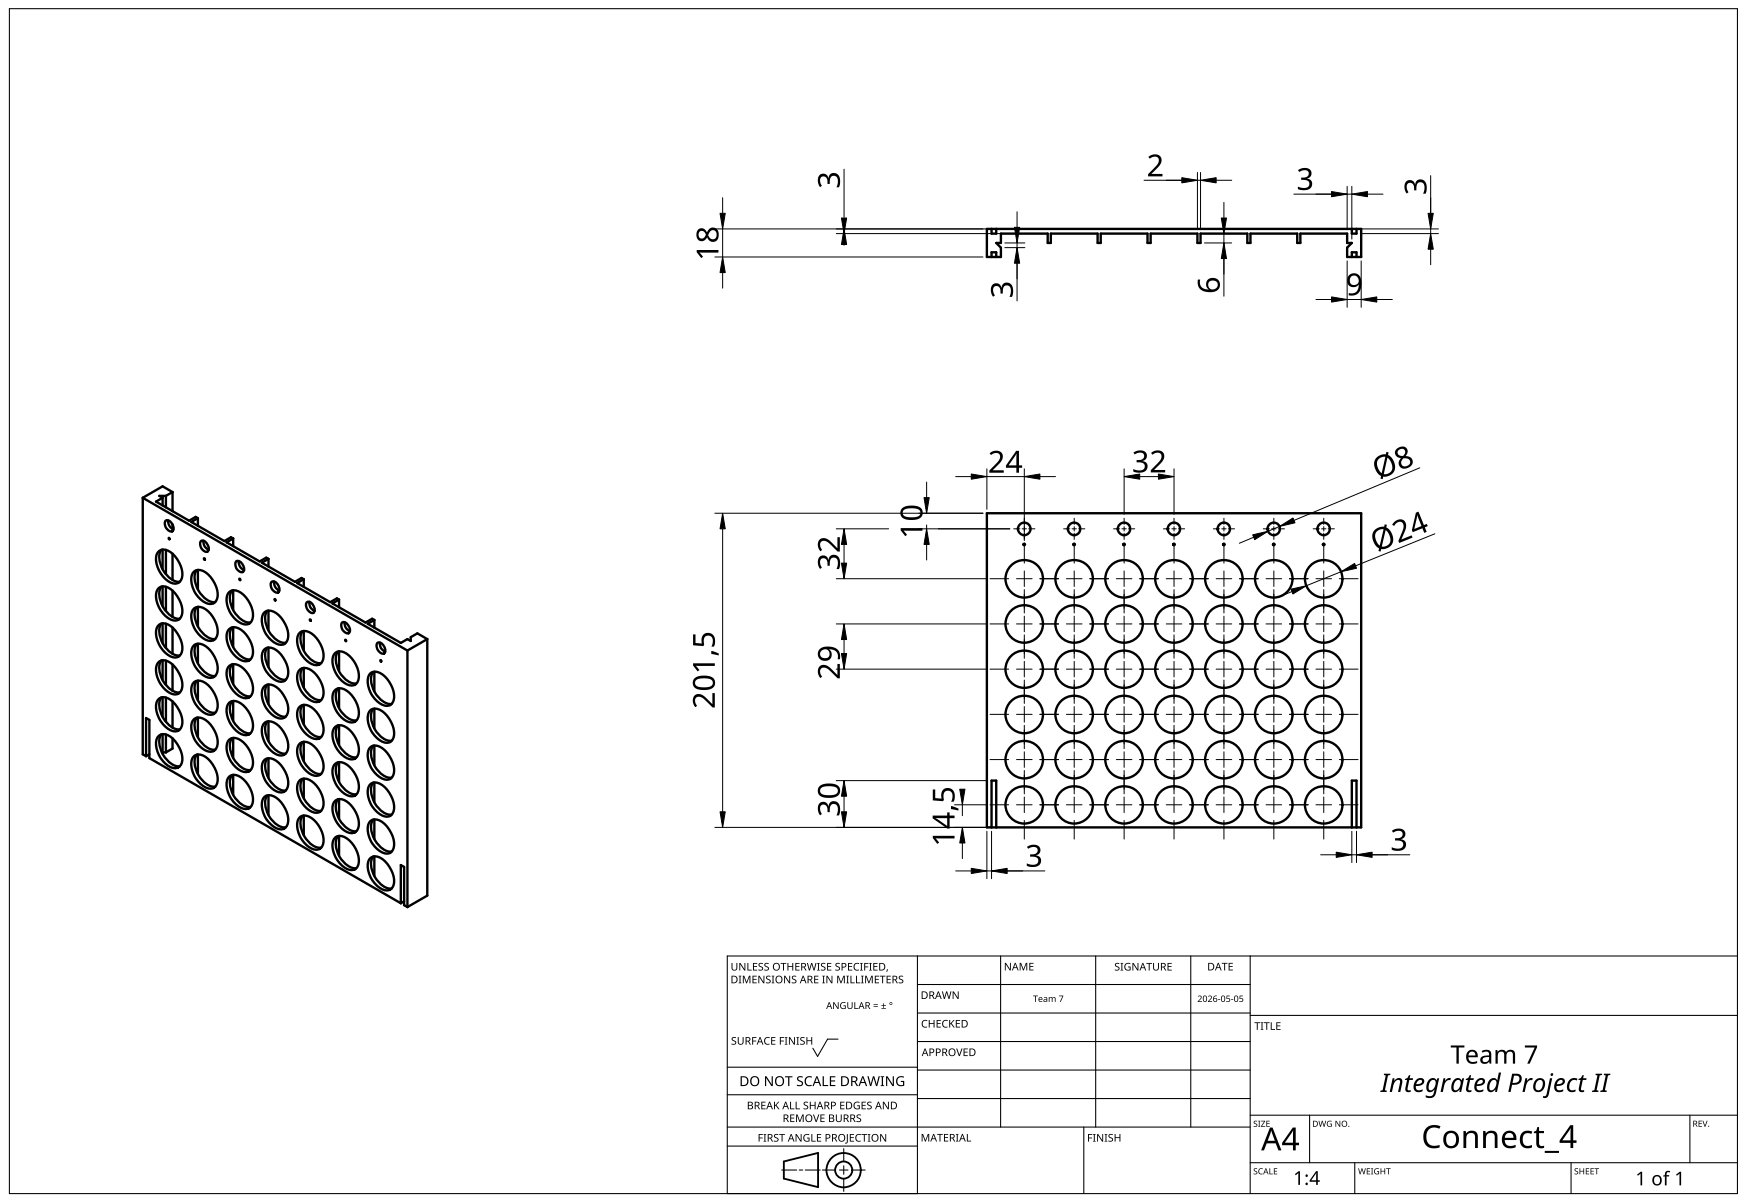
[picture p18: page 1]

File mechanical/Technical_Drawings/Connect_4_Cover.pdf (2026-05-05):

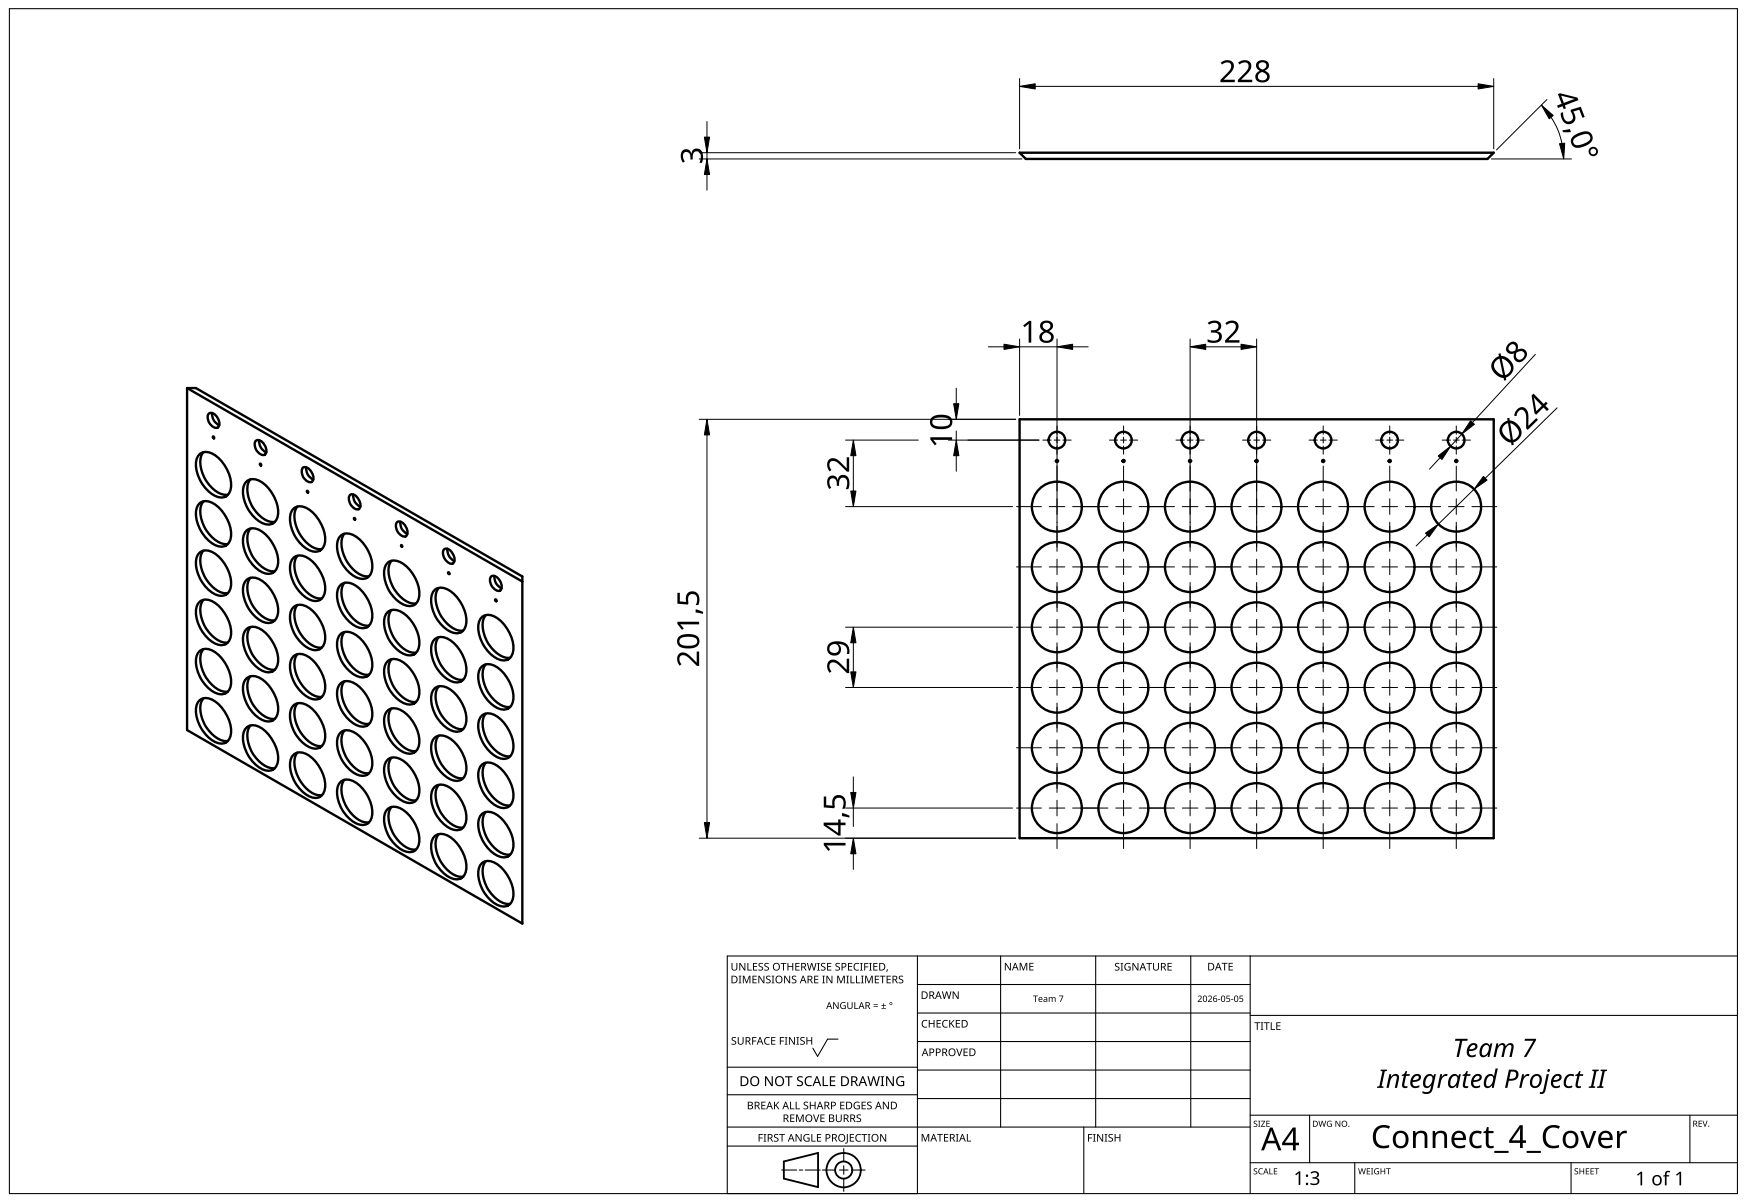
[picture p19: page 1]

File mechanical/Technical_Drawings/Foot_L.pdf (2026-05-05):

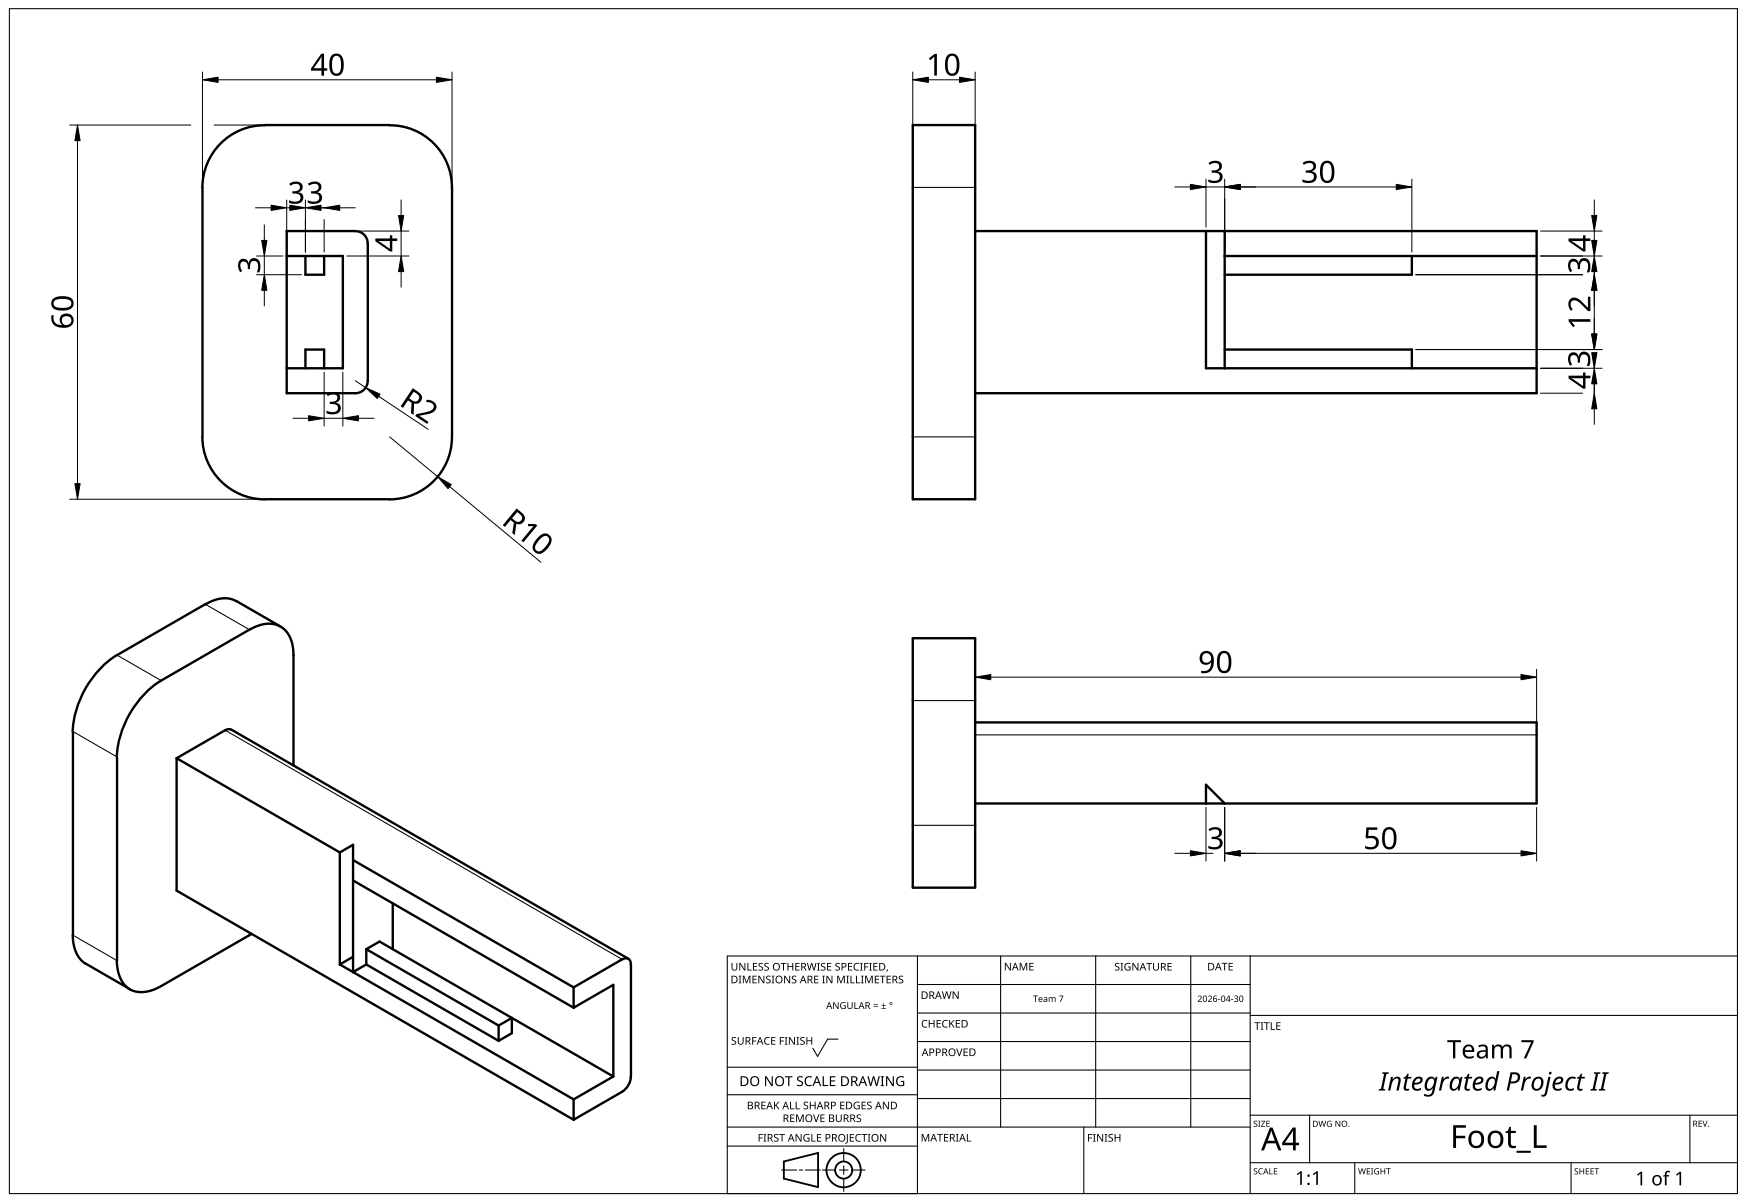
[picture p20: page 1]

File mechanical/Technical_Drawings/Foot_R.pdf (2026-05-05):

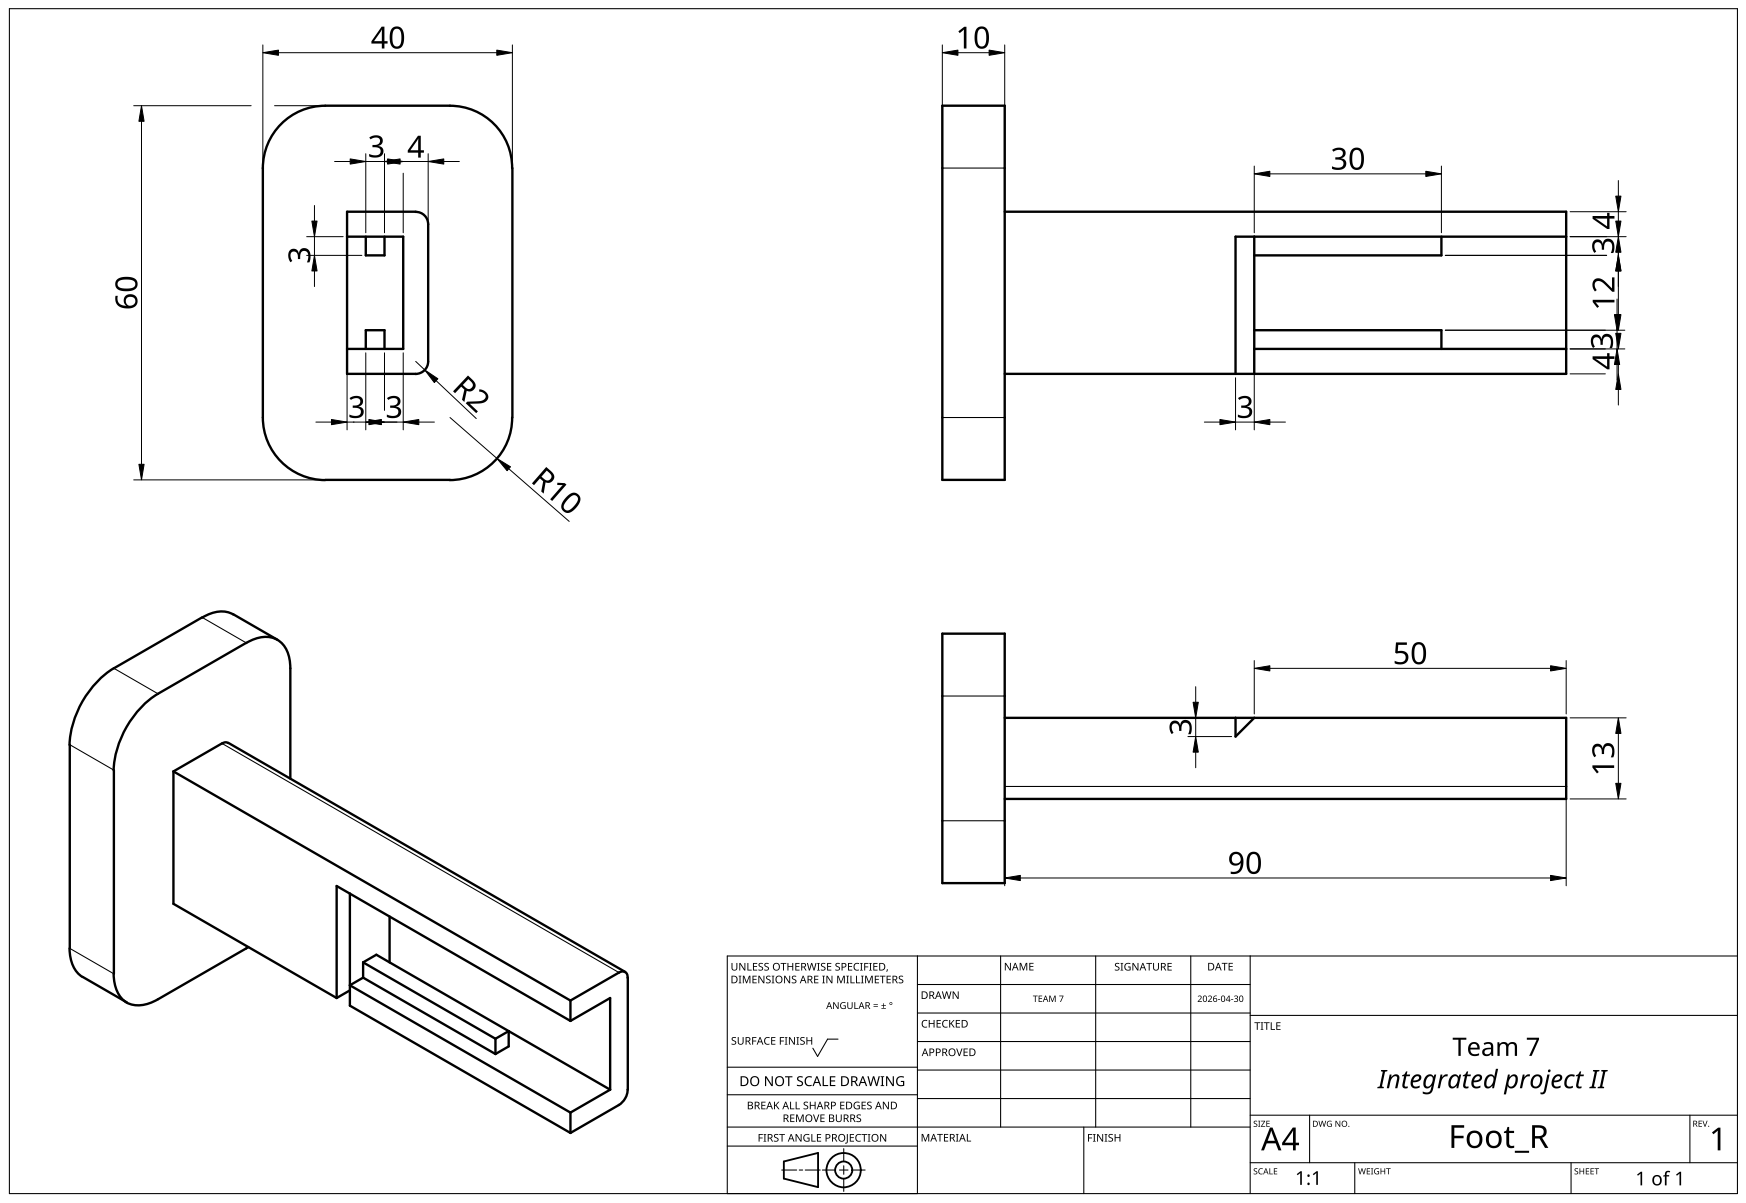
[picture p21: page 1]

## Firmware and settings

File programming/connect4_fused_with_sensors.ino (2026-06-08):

// CONNECT 4 - FUSED CODE (WITH SENSORS)
// Game logic + hardware (stepper motor + servo dispenser)
// + 7 photocell column sensors that detect the player's drop.
// The player no longer types the column: the sensors detect it.
// Team 7 - UVic-UCC - Projecte Integrat II - 2026
// WARNING: place the dispenser on COLUMN 7 by hand before powering on.
// Sensors are ACTIVE LOW (a passing piece pulls the pin to LOW).
// NOTE: GPIO35 is input-only and has NO internal pull-up, so column 7
// needs an EXTERNAL pull-up resistor (about 10k to 3V3).
// Libraries: AccelStepper (Mike McCauley) - ESP32Servo (Kevin Harrington)

#include "esp_sleep.h"
#include "soc/soc.h"           // needed to disable the brownout detector
#include "soc/rtc_cntl_reg.h"  // needed to disable the brownout detector
#include <AccelStepper.h>
#include <ESP32Servo.h>

// PINS
#define PIN_STEP   17    // A4988 STEP signal
#define PIN_DIR    16    // A4988 DIR signal
#define PIN_SERVO   4    // dispenser servo signal

// SENSOR PINS
// One photocell per column. Index 0 = column 1 ... index 6 = column 7.
#define NUM_SENSORS 7
const int sensors[NUM_SENSORS] = {13, 12, 14, 27, 26, 25, 33};

// MECHANICAL SETTINGS
#define STEPS_PER_MM       25    // 200 steps/rev divided by 8 mm lead
#define COLUMN_SPACING_MM  32    // distance in mm between two columns
#define SPEED             800    // steps per second
#define ACCEL             400    // steps per second squared

// SERVO ANGLES
#define SERVO_CLOSED  20    // gate closed (piece is held back)
#define SERVO_OPEN    80    // gate open   (piece drops)
#define SERVO_TIME   600    // ms the gate stays open

// OBJECTS
AccelStepper motor(AccelStepper::DRIVER, PIN_STEP, PIN_DIR);
Servo servo;

// GAME VARIABLES
char board[6][7];               // game board, '-' means empty
const int rows = 6;             // number of rows
const int cols = 7;             // number of columns
const char player = 'X';        // human player token
const char robot  = 'O';        // machine token
bool playerTurn;                // true = player's turn, false = robot's turn

// HARDWARE FUNCTIONS

// Steps needed to reach a given column (1-7). Column 7 is position 0.
long stepsForColumn(int col) {
  return (long)(7 - col) * COLUMN_SPACING_MM * STEPS_PER_MM;
}

// Move the dispenser to the requested column (1-7)
void moveToColumn(int col) {
  Serial.print(F("Motor -> column "));
  Serial.println(col);

  motor.setMaxSpeed(SPEED);
  motor.setAcceleration(ACCEL);
  motor.moveTo(stepsForColumn(col));
  while (motor.distanceToGo() != 0) motor.run();  // block until target reached
}

// Open the servo gate to release one piece, then close it again
void dispense() {
  delay(500);
  servo.write(SERVO_OPEN);   // open the gate
  delay(SERVO_TIME);         // keep it open so the piece falls
  servo.write(SERVO_CLOSED); // close the gate
  delay(300);
  Serial.println(F("Piece dispensed."));
}

// SENSOR FUNCTIONS

// Block until the player drops a piece and a column sensor fires.
// Returns the detected column (1-7). Sensors are ACTIVE LOW.
int waitForPlayerDrop() {
  // first make sure every sensor is clear (HIGH) before accepting a drop,
  // so a leftover blocked beam does not count as a new move
  bool clear = false;
  while (!clear) {
    clear = true;
    for (int i = 0; i < NUM_SENSORS; i++)
      if (digitalRead(sensors[i]) == LOW) clear = false;
    delay(5);
  }

  // now wait for a falling edge on any sensor
  while (true) {
    for (int i = 0; i < NUM_SENSORS; i++) {
      if (digitalRead(sensors[i]) == LOW) {       // piece detected
        delay(30);                                // debounce
        if (digitalRead(sensors[i]) == LOW) {     // confirm it is real
          int col = i + 1;                        // sensor index -> column
          while (digitalRead(sensors[i]) == LOW)  // wait for the piece to pass
            delay(5);
          delay(50);                              // small settle time
          return col;
        }
      }
    }
    delay(5);
  }
}

// BOARD FUNCTIONS

// Fill the whole board with empty cells
void initBoard() {
  for (int i = 0; i < rows; i++)
    for (int j = 0; j < cols; j++)
      board[i][j] = '-';
}

// Print the current board to the Serial Monitor
void showBoard() {
  Serial.println();
  Serial.println(F("+---+---+---+---+---+---+---+"));
  for (int i = 0; i < rows; i++) {
    Serial.print(F("| "));
    for (int j = 0; j < cols; j++) {
      Serial.print(board[i][j]);
      Serial.print(F(" | "));
    }
    Serial.println();
    Serial.println(F("+---+---+---+---+---+---+---+"));
  }
  Serial.println(F("  1   2   3   4   5   6   7  "));
  Serial.println();
}

// Drop a token into a column (1-7). Returns false if the column is full.
bool dropToken(int column, char token) {
  column--;                                          // convert to 0-based index
  if (column < 0 || column >= cols) return false;    // out of range
  for (int i = rows - 1; i >= 0; i--) {              // search from the bottom up
    if (board[i][column] == '-') {
      board[i][column] = token;
      return true;
    }
  }
  return false;                                      // column already full
}

// Check whether a token has 4 in a row (any direction)
bool checkWin(char token) {
  // horizontal
  for (int i = 0; i < rows; i++)
    for (int j = 0; j <= cols - 4; j++)
      if (board[i][j]   == token && board[i][j+1] == token &&
          board[i][j+2] == token && board[i][j+3] == token) return true;
  // vertical
  for (int i = 0; i <= rows - 4; i++)
    for (int j = 0; j < cols; j++)
      if (board[i][j]   == token && board[i+1][j] == token &&
          board[i+2][j] == token && board[i+3][j] == token) return true;
  // diagonal down-right
  for (int i = 0; i <= rows - 4; i++)
    for (int j = 0; j <= cols - 4; j++)
      if (board[i][j]     == token && board[i+1][j+1] == token &&
          board[i+2][j+2] == token && board[i+3][j+3] == token) return true;
  // diagonal down-left
  for (int i = 3; i < rows; i++)
    for (int j = 0; j <= cols - 4; j++)
      if (board[i][j]     == token && board[i-1][j+1] == token &&
          board[i-2][j+2] == token && board[i-3][j+3] == token) return true;
  return false;
}

// Return true when the top row is full (board is full)
bool boardFull() {
  for (int j = 0; j < cols; j++)
    if (board[0][j] == '-') return false;
  return true;
}

// ROBOT AI (win > block > random available column)

int robotLogic() {
  int c, row;

  // 1. take the winning move if one exists
  for (c = 1; c <= cols; c++) {
    if (board[0][c-1] != '-') continue;              // column full
    row = -1;
    for (int i = rows-1; i >= 0; i--)
      if (board[i][c-1] == '-') { row = i; break; }  // lowest free cell
    if (row == -1) continue;
    board[row][c-1] = robot;                         // simulate the move
    bool win = checkWin(robot);
    board[row][c-1] = '-';                           // undo the simulation
    if (win) return c;
  }

  // 2. block the player if they are about to win
  for (c = 1; c <= cols; c++) {
    if (board[0][c-1] != '-') continue;
    row = -1;
    for (int i = rows-1; i >= 0; i--)
      if (board[i][c-1] == '-') { row = i; break; }
    if (row == -1) continue;
    board[row][c-1] = player;                        // simulate player's move
    bool win = checkWin(player);
    board[row][c-1] = '-';
    if (win) return c;
  }

  // 3. otherwise pick a random available column
  int tries = 0;
  do {
    c = random(1, cols + 1);
    tries++;
    if (tries > 100) return -1;                      // no column available
  } while (board[0][c-1] != '-');

  return c;
}

// MATCH CONTROL

// Ask the player whether they want to play again (S = yes, N = no)
bool askRestart() {
  Serial.println(F("Play again? (S/N)"));
  while (true) {
    if (Serial.available() > 0) {
      char r = Serial.read();
      if (r == 'S' || r == 's') return true;
      if (r == 'N' || r == 'n') return false;
    }
  }
}

// Handle the end of a match: print the result and either restart or sleep
void endMatch(const char* message) {
  Serial.println();
  Serial.println(F("============================"));
  Serial.println(message);
  Serial.println(F("============================"));
  delay(2000);

  if (askRestart()) {
    // the dispenser must be put back on column 7 by hand
    Serial.println(F("Put the dispenser back on column 7 and press S."));
    while (true) {
      if (Serial.available() > 0) {
        char r = Serial.read();
        if (r == 'S' || r == 's') break;
      }
    }
    initBoard();
    motor.setCurrentPosition(0);   // reset: dispenser is on column 7

    Serial.println(F("Do you want to start? (S/N)"));
    while (true) {
      if (Serial.available() > 0) {
        char r = Serial.read();
        if (r == 'S' || r == 's') { playerTurn = true;  Serial.println(F("You start.")); break; }
        if (r == 'N' || r == 'n') { playerTurn = false; Serial.println(F("Robot starts.")); break; }
      }
    }
    showBoard();
  } else {
    Serial.println(F("See you soon!"));
    esp_deep_sleep_start();        // put the ESP32 to sleep
  }
}

// SETUP

void setup() {
  WRITE_PERI_REG(RTC_CNTL_BROWN_OUT_REG, 0);  // disable the brownout detector
  Serial.begin(9600);
  randomSeed(esp_random());

  // configure every sensor pin with the internal pull-up
  // (GPIO35 has no internal pull-up: add an external one)
  for (int i = 0; i < NUM_SENSORS; i++)
    pinMode(sensors[i], INPUT_PULLUP);

  // motor: current position = column 7 (placed by hand)
  motor.setMaxSpeed(SPEED);
  motor.setAcceleration(ACCEL);
  motor.setCurrentPosition(0);

  // servo: start with the gate closed
  servo.attach(PIN_SERVO);
  servo.write(SERVO_CLOSED);

  Serial.println(F("============================"));
  Serial.println(F("  CONNECT 4 - TEAM 7 UVIC  "));
  Serial.println(F("============================"));
  Serial.println(F("The dispenser must be on column 7."));

  initBoard();

  Serial.println(F("Do you want to start? (S/N)"));
  while (true) {
    if (Serial.available() > 0) {
      char r = Serial.read();
      if (r == 'S' || r == 's') { playerTurn = true;  Serial.println(F("You start.")); break; }
      if (r == 'N' || r == 'n') { playerTurn = false; Serial.println(F("Robot starts.")); break; }
    }
  }
  showBoard();
}

// MAIN LOOP

void loop() {

  // global draw check (just in case)
  if (boardFull()) {
    endMatch("DRAW! The board is full.");
    return;
  }

  if (playerTurn) {
    // PLAYER'S TURN
    // The player drops a piece on the real board and the column
    // sensors detect which column it fell into (no typing needed).

    Serial.println(F("Drop your piece on the board..."));

    int col = waitForPlayerDrop();      // blocks until a sensor fires
    Serial.print(F("Sensor detected -> column "));
    Serial.println(col);

    if (dropToken(col, player)) {
      showBoard();

      if (checkWin(player)) { endMatch("YOU WON!"); return; }
      if (boardFull())      { endMatch("DRAW!");    return; }
      playerTurn = false;

    } else {
      // the detected column is already full in the virtual board
      Serial.println(F("That column is full! Drop in another one."));
      delay(500);
    }

  } else {
    // ROBOT'S TURN
    // Compute the column -> move the motor -> dispense the piece.

    Serial.println(F("Robot's turn..."));
    delay(500);

    int col = robotLogic();
    if (col == -1) { endMatch("DRAW!"); return; }

    moveToColumn(col);          // move the physical dispenser
    dispense();                 // open the servo and release the piece
    dropToken(col, robot);      // update the virtual board

    Serial.print(F("Robot -> column "));
    Serial.println(col);
    showBoard();

    if (checkWin(robot)) { endMatch("THE MACHINE WON!"); return; }
    if (boardFull())     { endMatch("DRAW!");            return; }

    playerTurn = true;
  }
}

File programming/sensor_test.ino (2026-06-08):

// CONNECT 4 - SENSOR TEST
// Standalone sketch to check the 7 column photocells.
// Each sensor is ACTIVE LOW: it reads 0 (LOW) when a piece blocks it
// and 1 (HIGH) when the beam is clear.
// Open the Serial Monitor at 115200 baud and watch the readings.
// Team 7 - UVic-UCC - Projecte Integrat II - 2026
// NOTE: GPIO35 is input-only and has NO internal pull-up, so column 7
// needs an EXTERNAL pull-up resistor (about 10k to 3V3).

// PINS
// One photocell per column. Index 0 = column 1 ... index 6 = column 7.
#define NUM_SENSORS 7
int sensors[NUM_SENSORS] = {13, 12, 14, 27, 26, 25, 33};

// SETUP

void setup() {
  Serial.begin(115200);
  delay(1000);
  Serial.println("Photocell test - they detect on LOW");

  // configure every sensor pin with the internal pull-up
  for (int i = 0; i < NUM_SENSORS; i++) {
    pinMode(sensors[i], INPUT_PULLUP);
  }
}

// MAIN LOOP

void loop() {
  // print the state of every sensor on a single line
  for (int i = 0; i < NUM_SENSORS; i++) {
    Serial.print("C");
    Serial.print(i + 1);                 // human-friendly column number
    Serial.print(" GPIO");
    Serial.print(sensors[i]);            // physical pin
    Serial.print(" = ");
    Serial.print(digitalRead(sensors[i]));  // 0 = blocked, 1 = clear
    Serial.print("   ");
  }
  Serial.println();
  delay(300);                            // refresh rate
}

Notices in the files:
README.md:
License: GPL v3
